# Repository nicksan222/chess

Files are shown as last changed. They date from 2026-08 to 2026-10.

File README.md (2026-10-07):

<div align="center">

Chess logo: the smart chessboard seen from above, with a knight's move glowing through its tiles

# Chess

### A physical chessboard with software in its bones.

**64 magnetic sensors · 64 RGB lights · one Raspberry Pi · zero hidden magic**








[**Explore the hardware**](hardware/README.md) · [**Read the architecture**](docs/architecture.md) · [**Build from source**](docs/development.md) · [**Contribute**](CONTRIBUTING.md)

<a href="hardware/cad/generated/board-assembly-finished.png">
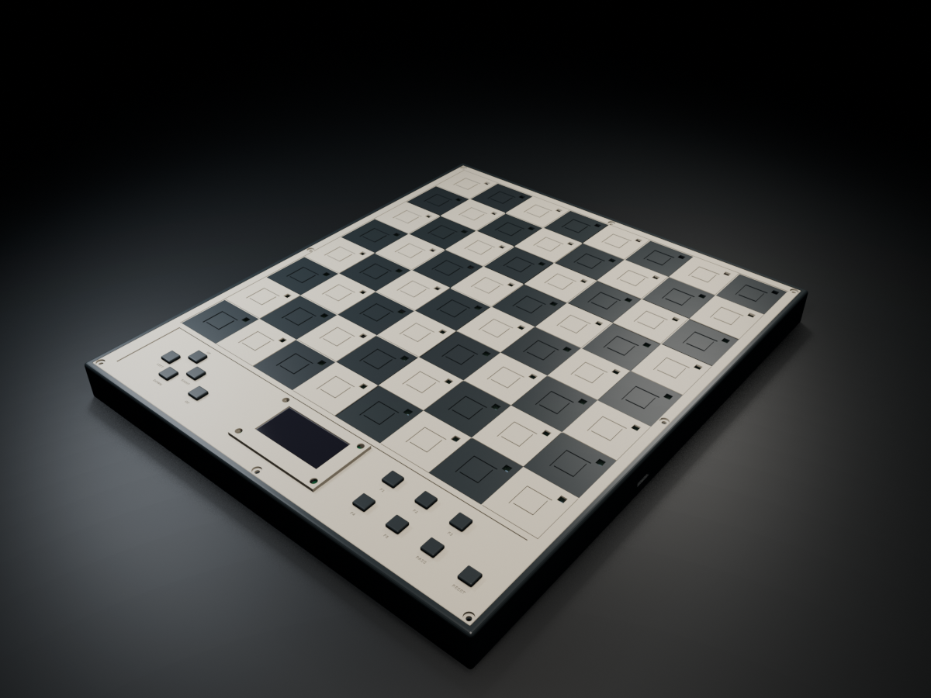
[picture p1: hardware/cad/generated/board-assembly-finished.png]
Generated Blender render of the finished open-source smart chessboard
  
</a>

<sub>Not a product mockup—the render above is generated from the <a href="hardware/cad/generated/board-assembly.blend">Blender assembly model in this repository</a>.</sub>

</div>

## About

Chess is an open-source smart chessboard designed to make the physical game
programmable. The design gives every square its own magnetic piece sensor and
clocked RGB light, ready to illuminate moves, threats, prompts, or entirely new
game modes. A Raspberry Pi Zero 2 W is intended to run the board directly in
Rust—there is no microcontroller, companion firmware, or private protocol in
the middle.

The interesting part is not only the board. Its mechanical dimensions,
electrical connectivity, firmware pin maps, KiCad project, Blender models, BOM,
and review images are generated from version-controlled contracts. Change a
measurement or signal once, regenerate, and let tests catch disagreement across
the stack.

| | |
|---|---|
| **Sense** | 64 DRV5032FC Hall sensors, eight compact polled TCA9554 banks |
| **Glow** | 64 individually addressable SK9822 RGB LEDs |
| **Think** | Raspberry Pi Zero 2 W targeting Rust on a Yocto Linux image |
| **Interact** | 12 labelled physical buttons and a 2.42-inch monochrome I²C OLED |
| **Build** | One 320 × 380 mm PCB, case, plate and twelve printable button caps |
| **Design** | Python contracts → KiCad 9 + Blender 4.5 + firmware mappings |

## Peek under the board

<table>
  <tr>
    <td width="58%">
      <a href="hardware/cad/generated/board-assembly-open.png">
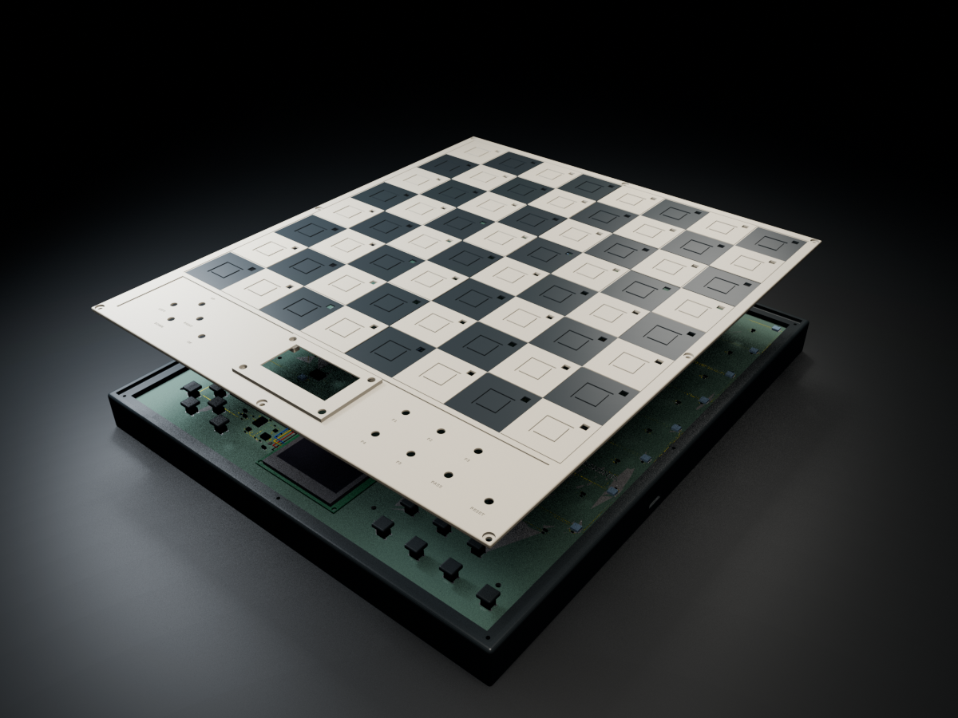
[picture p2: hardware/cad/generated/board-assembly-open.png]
Generated exploded Blender render showing the tile plate, PCB, and case
        
      </a>
    </td>
    <td width="42%">
      <a href="hardware/pcb/generated/board-top.png">
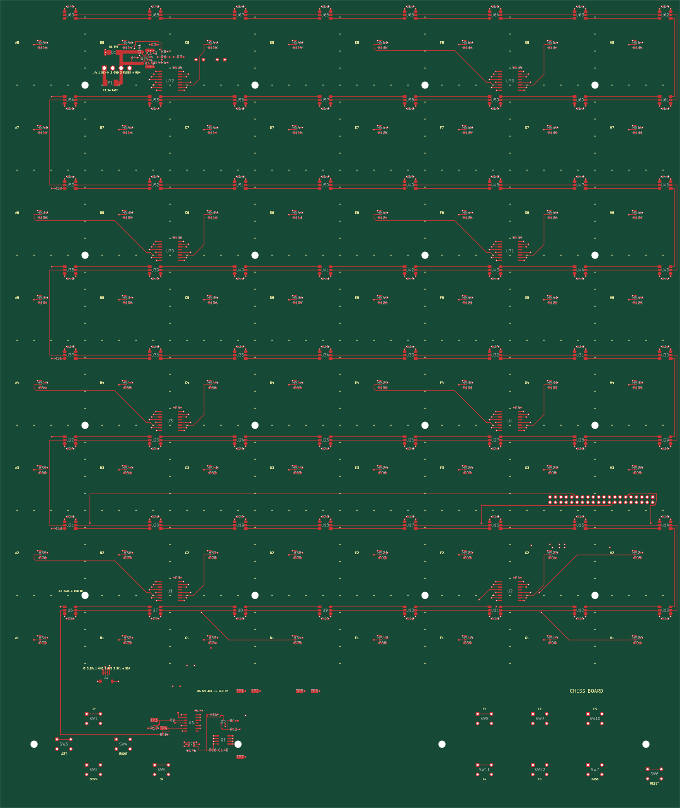
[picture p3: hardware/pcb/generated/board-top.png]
Generated KiCad top view of the smart chessboard PCB
        
      </a>
    </td>
  </tr>
  <tr>
    <td align="center"><strong>Two printed parts. One PCB. No per-square wiring harness.</strong></td>
    <td align="center"><strong>Every square gets a sensor and an LED.</strong></td>
  </tr>
</table>

The visuals are review artifacts, not hand-drawn diagrams. Open the
[Blender assembly](hardware/cad/generated/board-assembly.blend), inspect the
[KiCad board](hardware/pcb/generated/chess-board.kicad_pcb), browse the
[generated schematic](hardware/pcb/generated/schematic/chess-board.svg), or
check every exact part in the [generated BOM](hardware/pcb/generated/bom.csv).

## Why this is fun to hack on

| Hardware you can reason about | Software with clean seams | A workflow built for changes |
|---|---|---|
| No second processor and no opaque wire protocol. The Pi talks to I²C expanders, SPI LEDs, GPIO buttons, and the display directly. | The chess engine, menu model, persistence, and Pi application live in separate Rust crates. | One devcontainer pins Rust, Ruff, KiCad, Blender, and Just. CI checks code, connectivity, layout, CAD, and the AArch64 firmware graph. |

```mermaid
flowchart LR
    P["Magnetic pieces"] --> H["64 × Hall sensors"]
    H --> E["8 × TCA9554 banks (2×4)"]
    E --> PI["Raspberry Pi Zero 2 W"]
    PI --> R["Rust chess + board logic"]
    PI --> L["64 × RGB LEDs"]
    PI --> UI["OLED + 12 buttons"]
```

Read the [architecture notes](docs/architecture.md) for the boundaries and the
[hardware design](docs/hardware.md) for the component choices behind them.

## Repository tour

| Path | What is inside |
|---|---|
| [`apps/firmware`](apps/firmware) | The Raspberry Pi process, system integration, and Yocto image |
| [`crates`](crates/README.md) | Chess rules, menu state, persistence, logging, and shared Rust code |
| [`hardware/shared`](hardware/shared) | The source of truth for dimensions, parts, wiring, and mappings |
| [`hardware/pcb`](hardware/pcb) | PCB definition, routing, validation, KiCad project, and BOM |
| [`hardware/cad`](hardware/cad) | Parametric enclosure generators, Blender models, and renders |
| [`docs`](docs/README.md) | Architecture, fabrication, power, assembly, and development guides |

## Start hacking

Clone the repository, open it in the included
[development container](.devcontainer/README.md), and then use its pinned
toolchain:

```bash
just --list       # discover everything the repo can do
just precommit    # fast code + hardware validation
just generate     # regenerate CAD and PCB review artifacts
just check        # run routine repository-wide validation
```

Physical-release and Linux-image validation remain explicit, separate gates:

```bash
just pcb-release
just firmware-check
```

Prefer a smaller loop? Every app, crate, and hardware domain owns its own
`justfile`:

```bash
just --justfile crates/chess/justfile check
just --justfile hardware/pcb/justfile review
just --justfile hardware/cad/justfile generate
```

See [`docs/development.md`](docs/development.md) for the full workflow.

Coding assistants can use the existing [Pi setup](.pi/README.md) or the optional
[Claude Code / Herdr team](.agents/team/README.md). Rebuild the devcontainer,
run `claude auth login`, then `just agents-doctor` and `just agents`.
`just agents` starts the eight-role engineering team, including hardware, mechanical
and firmware engineers. Manufacturing, test and DevOps specialists are available on
demand; provider permissions remain on by default.

## Project status

> [!IMPORTANT]
> **The current design is ready for review, not yet physically proven.** The
> mechanical design and `D-PROTOTYPE` PCB generate successfully, and automated
> DRC, connectivity, schematic parity and modeled electrical checks pass;
> meaningful ERC still requires declared electrical pin roles. No
> complete board has been built yet. Prototype one sensor/LED square before
> ordering the full PCB.

The chess model and supervised firmware process exist. Hardware workers,
provisioning workers, and final physical validation are still open territory.
That makes this a particularly good time to challenge assumptions and shape the
project rather than only polish a finished product.

## Pick a quest

- **Firmware:** connect the Rust application to real Linux character devices.
- **Simulator:** make board behavior fast to test without a soldering iron.
- **Electronics:** review sensing, power, routing, and manufacturability.
- **Mechanical:** test clearances, print strategy, materials, and light diffusion.
- **Docs:** turn a pile of generated artifacts into a delightful build journey.

Start with [`CONTRIBUTING.md`](CONTRIBUTING.md), bring large ideas to
[Discussions](https://github.com/nicksan222/chess/discussions), and use the issue
forms for focused bugs or features. First-time contributors are very welcome.

---

<div align="center">

**Build it. Break it. Teach it a new game.**

Released under the [MIT License](LICENSE) · Please follow the
[Code of Conduct](CODE_OF_CONDUCT.md) · Report security issues via
[`SECURITY.md`](SECURITY.md)

</div>

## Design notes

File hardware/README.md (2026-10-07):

# Hardware

This directory contains the shared physical contract, manufacturable PCB, and
mechanical design:

- **`shared/`** — tool-independent dimensions, component identities, wiring,
  mappings, and host GPIO assignments.
- **`pcb/`** — reviewed connectivity, bill of materials, footprints, placement,
  routing, Gerber and Excellon fabrication output.
- **`cad/`** — printable enclosure and tile plate generated with Blender.

There is intentionally no separate electronics/schematic domain. The PCB is the
electrical design, and `pcb/board/board.py` composes its explicit connectivity
contract from typed components through the harness. The expanded netlist is generated output. Run `just --justfile hardware/pcb/justfile review` to validate and generate review and fabrication files. Manufacturing approval remains pending; `release` refuses approval.

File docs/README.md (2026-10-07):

# Project documentation

This directory contains design and development documentation that spans multiple
code or hardware areas. Component-local instructions stay with their component.

- [`architecture.md`](architecture.md) — how the parts relate, and why the board
  carries no microcontroller
- [`hardware.md`](hardware.md) — the board: sensing, LEDs, bus assignment
- [`fabrication.md`](fabrication.md) — how Gerbers are generated, and what the
  toolchain does and does not verify
- [`power.md`](power.md) — the 5 V rail and where the current goes
- [`cad.md`](cad.md) — printed parts and mechanical conventions
- [`host.md`](host.md) — the software on the Raspberry Pi, including WiFi setup
- [`assembly.md`](assembly.md) — what to order and the order to solder it in
- [`bring-up.md`](bring-up.md) — the ordered first-article checklist for the board
- [`development.md`](development.md) — the supported repository workflow

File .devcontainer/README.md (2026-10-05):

# Development container

This directory owns the reproducible VS Code / Cursor development environment.
The Dockerfile installs every toolchain the jobs need: Blender, KiCad 9, Ruff,
and the Rust components. Open the repository and run **Dev Containers:
Reopen in Container**, or drive it from the
[`devcontainer` CLI](https://github.com/devcontainers/cli):

```sh
devcontainer up --workspace-folder .
devcontainer exec --workspace-folder . just pcb
devcontainer exec --workspace-folder . just cad
devcontainer exec --workspace-folder . just quality
devcontainer exec --workspace-folder . just test
devcontainer exec --workspace-folder . just check
```

The image provides:

- Node.js 22, Bun 1.4, and every agent harness: pinned Claude Code and Herdr in the
  image, pinned [Pi](https://pi.dev/) and Codex installed during container creation
  (creation fails if any is missing), plus Herdr's Claude/Codex/Pi status hooks and
  the Reviewr panel; `just agents` asks whether the optional
  [agent team](../.agents/team/README.md) runs in Claude Code or Pi;
- a Bun-managed `.pi` TypeScript project with pinned Pi API types, workspace
  IntelliSense, and `bun run --cwd .pi check` validation for project extensions;
- stable Rust with `rustfmt`, Clippy, Just, and the AArch64 GNU target/linker;
- Ruff for CAD, PCB, and shared Python;
- KiCad 9 with `kicad-cli` and `pcbnew`;
- a checksum-verified Blender at `/opt/blender`;
- X11/GL/EGL, Mesa, Xvfb, and `xauth` so headless Blender can render;
- an in-container Docker daemon for Yocto metadata validation, plus native build,
  USB, and udev development libraries;
- rust-src, Pylance, YAML, ShellCheck, Docker, Cargo.toml, TOML, LLDB,
  Markdown, and GitHub Actions editor integration.

CI prebuilds this image, pushes it to GHCR, then runs Python, CAD, PCB, and Rust as
parallel `devcontainer exec` jobs against that digest. Subsequent
prebuilds reuse the image layers when the Dockerfile is unchanged.

Container creation configures the repository pre-commit hook, installs Pi/Codex,
and configures Herdr integrations without starting models. Claude Code is installed
in the image. Separate `chess-claude`, `chess-codex` and `chess-herdr` volumes keep
provider credentials and runtime configuration across rebuilds. Run
`claude auth login` inside the container (or forward `CLAUDE_CODE_OAUTH_TOKEN`).
Accept workspace trust manually. Host API credentials may select API billing;
unset `ANTHROPIC_API_KEY` before opening the container for subscription-only use.
No host credential directories are mounted and no secrets are copied into the image.
Credentials for every built-in Pi API-key provider are forwarded from matching
host environment variables without writing secrets to the repository. Pi's
`~/.pi/agent` directory uses the persistent `chess-pi-agent` Docker volume, so
credentials created with `pi` and `/login` survive container rebuilds. The
`pi-worktrees` package stores managed worktrees in the persistent
`chess-pi-worktrees` volume, preserving uncommitted agent work across container
recreation. Export provider variables on the host before opening the container; see Pi's
[provider documentation](https://github.com/earendil-works/pi-mono/blob/main/packages/coding-agent/docs/providers.md)
for the supported names and cloud-provider settings.

Host-only fallback downloads (`.cache/blender`, `.cache/pcb`) exist for people
who run the tools outside the container.

After create, the first VS Code terminal greets you with a 👋 welcome: toolchain
versions, which agents are signed in, and the commands below. Bring it back with
`just welcome`.

```sh
just welcome               # toolchain/login status and starter commands
bun run --cwd .pi check    # type-check project Pi extensions
pi                         # start the coding agent; use /login for OAuth
claude auth login          # persistent Claude login; no automatic sign-in
just agents-doctor         # tools/login check, no model request
just agents                # start the eight-role team
just agents-restart        # restart it, task handoff kept
just agents-stop           # stop it
just agents-test           # offline launcher/configuration tests
just pcb                    # test, then generate PCB review output
just cad                    # test, then generate CAD output
just quality                # lint and format-check every package
just firmware-binary        # link the firmware for AArch64
just test                   # test every package
just check                  # all domains, sequentially
```

Host-specific device access and hardware flashing policy do not belong in the
portable baseline container configuration.

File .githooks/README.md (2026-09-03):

# Git hooks

This directory owns version-controlled Git hooks. The pre-commit hook runs
`just precommit`, which composes package-owned recipes while skipping CAD
renders and PCB fabrication output. `.pre-commit-config.yaml` invokes the same
gate for `pre-commit run`.

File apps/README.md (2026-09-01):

# Applications

This directory contains runnable applications. Reusable concepts belong in shared
crates rather than application packages.

`firmware` is the Raspberry Pi Linux appliance and its product process. The
board carries no microcontroller or bare-metal target; see
[`../docs/architecture.md`](../docs/architecture.md).

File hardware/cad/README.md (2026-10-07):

# Mechanical design

CAD follows the PCB domain: concrete components, one composed board, a reusable
harness and generated output. Shared dimensions remain in `hardware/shared`.

```
components/  one physical component per file; printable parts and electronics
board/       Board definition, the single generate.py entry point, specific tests
harness/     registry, Blender geometry/rendering, validation and automatic checks
generated/   owning .blend models, assembly, PNGs and verification manifest
```

`board/board.py` owns the case, plate, imported PCB assembly, off-board host and
OLED, rear jack, rocker, mating plug envelopes and all eight harness conductors. Repeated PCB parts remain individually selectable by square or control name:
`board.sensors["A1"]`, `board.leds["H8"]`, `board.buttons["OK"]`.
The PCB generator attaches package-local STEP models and exports `chess-board.glb`.
Blender imports that file's substrate, holes, copper, artwork and component meshes;
it does not rebuild PCB electronics. Component references survive as `PCB_SW1`,
`PCB_SW1_Body`, etc. Package geometry and model fidelity belong to PCB definitions.
Most models are explicitly dimension-based envelopes; the switch has its declared
housing and actuator. Detailed supplier CAD and physical validation remain pending.

Shared supplier dimensions, mounting interfaces and layout measurements remain
readable source definitions. CAD uses them for enclosure fits and off-board
parts; it does not infer these values from imported Blender mesh bounds.

There are fourteen printed parts: twelve button caps plus the case and plate. `components/printable/board_case.py` owns the
344 × 404 × 30 mm open case; `tile_plate.py` owns the 335 × 395 mm checkerboard
and control bezel, including its raised screen and underside mounting ledges. Their cuts, supports, screw positions and assembly coordinates
retain their positions. Each square has an 18 × 18 mm square ring channel,
0.8 mm deep, surrounding a 14 × 14 mm island at the square's original surface
height. A solid 19.6 × 19.6 mm underside support covers the Hall sensor and
reinforces the channel floor. Future pieces use a matching square ring foot:
17.5 mm outside, 14.5 mm inside, projecting 0.6 mm below the base. Both interfaces
come from `shared/dimensions/tile_plate.py` and include clearance on both sides.

Each LED has a 4.6 mm square through-window above its actual emitter position.
Controls use a left D-pad, separate OK, a right function group (F1-F5 and PASS),
and an isolated Reset. Positions and render legends read the same shared button
identities used by the PCB and GPIO mapping; moving switches requires regenerating
both PCB and CAD; CAD generation automatically refreshes a stale PCB export.

The 60 mm control strip is recessed 1 mm. A 2.42-inch MC242GW monochrome OLED
uses the same four-wire I²C interface and 128 × 64 graphics API. The module's
supplied pin header is omitted: solder the harness directly, leaving RES open
for the module's onboard reset circuit. Its screen sits above the panel in a
bezel, with four carrier mounting ledges and blind screw pilots and four top access holes. Carrier, glass,
mounting holes and underside envelopes follow the supplier drawing. Screw size,
print tolerances and retention still require a physical prototype.

Twelve separate printable caps fit the existing TL1105 switch stems. Their
labels are recessed into the actual panel mesh. D-pad, OK, function buttons,
PASS and RESET share their coordinates with the PCB and GPIO definitions.
The four OLED conductors remain 180 mm long with dressing/service slack.
Square faces and locating channels use charcoal and ivory presentation materials.
The assembly imports those exact meshes rather than rebuilding
them. Coordinates are centered on the playing area; PCB coordinates are translated
once on the imported KiCad assembly, converting glTF metres to our millimetre scene.

## Generate and check

```sh
just --justfile hardware/cad/justfile check-fast  # lint, types and Python tests
just --justfile hardware/cad/justfile generate    # complete models and renders
just --justfile hardware/cad/justfile check      # both
```

`board/generate.py` checks PCB/shared source fingerprints, actual exporter versions,
and hashes of the saved PCB, GLB and PCB-owned `pcb-components.json`. CAD source
provenance includes its `justfile` and the shared `hardware/build_support.py` publisher.
The selected Blender executable is queried directly and publication verifies that the
worker recorded the same runtime version. Missing, altered or stale output triggers the full checked PCB pipeline.
All expected component references must have meshes in the GLB. The current export,
its `3d-models.json` fidelity/provenance report, and its validated metadata snapshot
cross the host Python / Blender Python 3.11 boundary. Run inside the devcontainer,
which supplies KiCad, CadQuery 2.6.1 for STEP generation, and Blender 4.5.

`just generate` and CI run PCB review before CAD, using the same checked export.
The standalone CAD command refreshes that dependency only when needed. CI runs
one sequential hardware job and retains separate successful PCB and CAD outputs.

The generator builds the case, builds the plate, assembles their saved models,
checks fit, renders the finished/open views and writes `manifest.json`. It publishes
one complete artifact set atomically; a failed model, render, check or missing output
leaves previous output untouched. Do not hand-edit generated files.

Board-specific dimension/instance tests live in `board/tests`. Generic registry,
publication and clearance checks live in `harness`, including negative regressions.
Every build checks actual PCB body heights, connector mating envelopes, case/bay
clearance, positive/manifold printable meshes, build volume and seated assembly fit.
The fit manifest records measured mesh dimensions, volumes and intersection results.
`board/tests/blender` runs inside the generation worker on the actual seated meshes,
checking all 64 square seats and LED windows, the lowered strip, button protrusion,
display sight line and render visibility. Electronics tests check actual positions,
rotations, mounting sides and body dimensions of every PCB instance, plus the
shared host/display dimensions, plus native PCB mounting holes and artwork.
The importer welds coincident shading vertices without moving the surface and
requires closed positive-volume solids before intersection checks. The worker saves
the finished inspection view, reopens that exact `.blend`, and only then runs the
native tests. Host pytest skips these native tests; every generation must run them
without skips before it publishes.

## Blender harness

`harness/base/blender` owns mesh operations, materials, studio setup, saving and
rendering. Boolean batches require disjoint cutters, and bevel radii must stay
below half the thinnest dimension: these prevent silent invalid geometry.
Materials are presentation choices rather than manufacturing specifications.

The pinned Blender toolchain uses a private Xvfb display when available. The
`setup` recipe can download a checksum-verified build into `.cache` outside the
container; `BLENDER_BIN` selects an existing installation. Ruff and strict
Basedpyright use Blender stubs; normal declarations and checks run without Blender.

Both printed parts exceed desktop printer beds and are intended for an FDM service.
Mesh checks do not prove shrinkage, supports, layer adhesion or physical operation.
Calibrated prints and physical clearance review remain pending; generated models
are review artifacts and do not constitute manufacturing approval.

The PCB generator owns the metadata snapshot as well as the meshes. CAD only
copies and reads the checked bundle; it validates the copied files and retries
once if concurrent PCB publication interrupts the copy. The frozen input GLB is
retained with the CAD outputs so the assembly can be reviewed independently.
`manifest.json` fingerprints CAD/shared source inputs and hashes every output,
including the snapshot. Atomic publication rejects missing or altered artifacts.

Rear power components and mating plugs use simplified dimension envelopes.
Every harness conductor retains its connector cavity, net, cut length and
proposed route length. Mesh checks cover enclosure, PCB and off-board collisions,
except same-reference solids and declared mating interfaces. An AABB broadphase
selects possible collision pairs before mesh booleans; remaining checks use a
0.01 mm³ numerical-noise tolerance, with connector endpoint allowances applied only
at their declared mating interfaces.
Unmodeled service slack, actual solder-pad locations on the OLED, cable bend radii,
connector latches and final wire dressing remain physical assembly checks.

The OLED mount uses four [M2.5 × 3 DIN 912 socket screws](https://www.newstarfastenings.com/en-gb/products/m25-x-3-socket-cap-screw-din-912-steel-129-self-finish),
with 4.5 mm heads and a 2 mm hex driver. The bezel's 5 mm access holes allow
installation from above. Calibrate/drill and tap the printed 2 mm pilots to M2.5
before installing the carrier; verify thread holding and screw-tip clearance on
a prototype. Screw models are not included in the electronics envelope render.

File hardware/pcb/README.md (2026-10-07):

# PCB authoring

The PCB has three source folders:

- `components/`: one concrete component per file, including its purchasing facts,
  land pattern and named connections to physical pins.
- `harness/`: reusable circuit declarations, SPICE conversion, native KiCad
  rendering and automatic component checks. KiCad type stubs live in
  `harness/typings/`.
- `board/`: just `board.py` (components, placement, layout and rules),
  `wiring.py` (copper intent), and `generate.py` (the single output pipeline).
  `board/tests/` holds specific electrical behavior tests using the harness.

`generated/` contains output, not source. Generate inside the devcontainer:

```sh
just --justfile hardware/pcb/justfile generate
# or
PYTHONPATH=hardware python3 -m pcb.board.generate
```

Open `generated/chess-board.kicad_pro` in KiCad. Generation writes the PCB,
connection schematics, BOM, expanded netlist, placement CSV, PDF/SVG/PNG previews,
ERC/DRC findings, a native `chess-board.glb` assembly, portable component STEP
models, `3d-models.json` provenance/fidelity, a manifest, and `chess-board-fabrication.zip`. The ZIP contains
all eight copper layers, masks, silkscreens, outline, paste layers and separate
plated/non-plated Excellon drill files. It validates exported schematic pin maps and
schematic/PCB parity before atomically replacing previous output.

The board owns its eight-layer stackup, four rail planes, mounting holes and
silkscreen in `board/board.py`. `board/wiring.py` declares routing intent with
`NetRoute` records (layer choices, widths and local areas); the harness supplies the obstacle-aware
multilayer router. Exact paths use `CopperPath` through named component pins.
`RoutingPlan` orders power connections, LED links and signal routes; execution lives entirely
in the harness. Package escape geometry and local clearance rules belong to each
component definition. There is no native routing implementation under `board/`.
Connections come from the components' pin maps. Generation checks native routed connectivity
and exports full-board copper SVGs and matching PNGs (using `rsvg-convert`).
`board-connections.svg` remains a separate logical airwire view.
Board pytest tests run ngspice against actual sensing and button components and
their pin maps. They cover every square, piece placement/removal, a move between
banks, startup bypass charging, crossed inputs, individual button presses,
three simultaneous presses, all buttons held, bounce and release. Button checks
explicitly supply an external 3.3 V bias through a declared source resistance;
this represents host GPIO pull-ups, not additional PCB components or guaranteed
Pi pull-up limits. Both `check` and generation collect all board tests with pytest.
Generation writes `electrical-checks/results.json`, `junit.xml` and `tests.log`;
failed, skipped or empty suites stop the export. Run them directly with
`python3 -m pytest hardware/pcb/board/tests` inside the devcontainer.
The models are ideal: magnetic margins, sensor sampling delay, I2C, firmware
debounce and electrical behavior outside the sensing/button circuits remain untested.

```sh
just --justfile hardware/pcb/justfile check          # lint, types, harness/catalog checks
just --justfile hardware/pcb/justfile review         # check, then generate authoring output
just --justfile hardware/pcb/justfile harness-tests
just --justfile hardware/pcb/justfile component-tests
just --justfile hardware/pcb/justfile component-checks
just --justfile hardware/pcb/justfile pr-report main
```

Automatic checks live in [harness/checks/](harness/checks/README.md). Documentation
checks use real HTTP requests. Shared products, dimensions and electrical
contracts in `hardware/shared/` remain authoritative.

Pin electrical roles, reassessed manufacturing constraints,
detailed supplier geometry, active-device simulations and physical evidence are still
pending. Previous engineering assumptions are retained in
[engineering assumptions](../../docs/pcb-assumptions.md) for reassessment, not as proof of
the new design. Fabrication files are generated locally for review; manufacturing
approval remains pending. The separate release command still refuses approval.

Repeated components are created in loops as separate instances. Select them by
square or bank: `board.sensors["A1"]`, `board.leds["H8"]`,
`board.sensor_bypasses["A1"]` or `board.sensor_banks["A1-D2"]`.
Their own pin maps remain the source of electrical connectivity. Routing can be
changed for one sensor without defining another component or reconnecting it:

```python
from dataclasses import replace
from shared.electronics.hall_sensor import HallSensorPin

sensor_net = board.sensors["A1"].net(HallSensorPin.ACTIVE_LOW_OUTPUT)
board.wiring = tuple(
    replace(route, width_mm=0.4) if route.net == sensor_net else route
    for route in board.wiring
)
```

The 3D pipeline is owned by the PCB harness. `ComponentDefinition.model_3d`
optionally declares package-local colored solids. Other products receive an
explicitly labeled envelope from their existing body dimensions. CadQuery writes
one STEP per product; the harness attaches `${KIPRJMOD}/models/...` references to
native footprints. KiCad then supplies board-side placement, rotation, mounting
height, holes, copper and artwork in the GLB. Missing component meshes fail the
export. CAD imports that exact artifact instead of maintaining electronic bodies.
These models do not claim supplier detail or physical manufacturing validation.

The PCB export also owns `pcb-components.json`: component bodies, mating envelopes,
contact positions and named sensor/LED/control groups for the Blender bridge.
`3d-models.json` binds that snapshot, native PCB and GLB to source and exporter
version fingerprints. Portable `Model3D`, `Solid3D` and `MatedZone` values are
available through `pcb.harness`; native conversion stays under `pcbnew`.

Assembly review outputs include `assembly-bom.csv` (grouped quantities, MPNs and
mounting types), `assembly-smd.csv` and `assembly-through-hole.csv` (disjoint
placement lists). `positions.csv` retains native XY/rotation conventions and adds
package identity from component definitions. `harness.md` and `harness-bom.csv`
cover the separate off-board wire assemblies. See `generated/assembly.md` for
assembler interpretation and the outstanding release requirements.

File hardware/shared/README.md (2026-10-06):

# Shared hardware definitions

This directory is the tool-independent contract between hardware domains.

- `dimensions/` separates shared measurements by physical object: `board.py`,
  `case.py`, `panel.py`, and `tile_plate.py`. `printing.py` owns process limits;
  `validation.py` checks fit across those objects. PCB routing rules and CAD
  presentation settings remain in their own domains.
- `components/<part>.py` owns each approved product: manufacturer, exact MPN,
  package, body metadata, and datasheet link. The package registry enumerates them.
- `electronics/` owns tool-independent component families and typed pin semantics,
  including `harness.py`, the cavity-by-cavity definition of the off-board power and
  OLED wiring harnesses (tests, BOM and `generated/harness.md` all read it).
- `dimensions/unverified.py` lists case/CAD dimensions that still rest on an unread
  datasheet or an unmeasured drawing; the PCB release gate imports it.
- `panel_buttons.py` owns each control button's position, typed header pin,
  switch reference, and routing priority.
- `hall_banks.py` owns compact bank membership, P-port order, labels, and address
  straps; dimensions and wiring consume it.
- `wiring.py` owns net names, host GPIO assignments, square-to-sensor mapping,
  and LED chain order.

Shared code must never import Blender, Schemdraw, Gerbonara, or KiCad. Domain
folders compose these definitions and own only rendering/tool behavior.

Shared Python is linted and format-checked with Ruff and strictly type-checked
with Basedpyright. Both explicit and inferred dynamic types are rejected. Run
`just --justfile hardware/shared/justfile check`; the root
`just precommit` and `just check` recipes compose it with the other packages.

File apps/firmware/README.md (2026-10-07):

# Firmware

This app contains the Raspberry Pi process and its Yocto build. The development
container includes the AArch64 linker and Rust target used by CI.

```sh
# Compile and link the complete Rust dependency graph for the Pi architecture.
just firmware-binary

# Validate or build the Yocto image; these commands require Docker.
just --justfile apps/firmware/justfile image-check
just --justfile apps/firmware/justfile image
```

The flashable files are written to `dist/firmware`.

## Runtime architecture

`src/runtime/` is the one event-driven application loop used by both the
executable and the runtime tests. Hardware adapters publish typed physical observations
through `src/events/`; Tokio channels never escape that module. `src/harness.rs` starts
the same runtime without physical adapters and provides an acknowledged
`trigger` operation, so tests never race the event loop or duplicate production
behavior.

`just --justfile apps/firmware/justfile test` runs unit tests and `tests/`: the
production runtime with injected hardware (`tests/runtime/`), display rendering
(`tests/display/`) and the command line. It needs no Docker or hardware. Scripted
GPIO cases cover all 12 button mappings, bounce, initially held buttons and read
failures. Product logic above the Linux adapters is tested against in-memory
fakes; the adapters themselves (NetworkManager through `nmrs`, GPIO through
`gpiocdev`) run only on the board, where real Wi-Fi, GPIO and display behaviour is
validated.
The Linux GPIO reader is available to callers but is not yet wired into the
production executable's startup.

`src/connectivity/` owns typed, presentation-agnostic Wi-Fi control. Its
`Connectivity` API reports status, scans access points, manages the WPA
provisioning hotspot, and joins open or WPA Personal networks. Product code sees
validated SSIDs, redacted passphrases, and domain results rather than command
arguments or NetworkManager types. The implementation uses the maintained `nmrs` D-Bus
client; no shell or `nmcli` process is involved. The Yocto image
includes NetworkManager Wi-Fi support, `wpa-supplicant`, and `dnsmasq` for
NetworkManager's shared hotspot mode. Captive-portal presentation and menu
transition wiring remain separate consumers of this module.

`src/menu/definition.rs` is the single product menu definition. It composes the
headless `menu` crate's primitives into the Play, Connection, Pairing, Update,
and Settings submenus. Leaf requests are typed but deliberately immediate and
non-blocking until their external modules define completion and cancellation
behavior; the menu crate remains product-neutral and performs no operation.
Each request has one placeholder integration file under `src/menu/transitions/`,
so future module ownership has an explicit location without entering the menu
definition or runtime loop.

`src/hardware/buttons.rs` and `src/hardware/debounce.rs` own polling, active-low
translation, and mechanical debounce. Call `start_subscription` with a GPIO
reader, then await `on_message` for debounced pressed/released transitions.
`hardware::linux_gpio::LinuxGpioReader` requests inputs with internal pull-ups
on a caller-selected Linux GPIO chip; the button adapter interprets a low level
as pressed. `with_external_bias` leaves line bias to the board instead of
requesting an internal pull-up. Callers do not inspect GPIO levels.

`src/hardware/display/` constructs a buffered SSD1309 driver for the installed MC242GW
2.42-inch 128×64 OLED at address `0x3C`. The four-wire I²C module supplies
power-on reset; allow 200 ms of stable power before initialization. Construction
and drawing perform no I/O; initialize, clear, flush and power retain the same API. It is
intentionally not attached to the runtime yet. Integration tests under
`tests/display/` capture the exact data packets emitted through I2C, decode the
transmitted frame, and compare it pixel-for-pixel with the externally maintained
`embedded-graphics-simulator`. Every display test writes a PNG result beside
the tests in `tests/display/screenshots/`.

The simulator verifies frame contents, not controller command semantics. Wokwi
can emulate an SSD1306 receiving real I2C traffic, but running this Raspberry Pi
firmware driver there requires a separate supported-microcontroller harness and
Wokwi CI credentials. No such harness is checked in because it would not execute
the production Pi I2C adapter.

The remaining hardware workers are not implemented yet. The board contract uses
polled TCA9554 input-port reads at eight addresses, not a GPIO sensor interrupt;
see [host acquisition](../../docs/host.md#reading-the-board). Reusable,
function-named GPIO identities and type-safe descriptors live in
`src/hardware/pins.rs`; OS-backed implementations live alongside them (currently
`src/hardware/linux_gpio.rs`). Unused header functions are deliberately absent.
`BoardPins` describes the three interfaces in the hardware wiring contract:
I2C for the shared bus, SPI for the LED chain, and direct GPIO button lines.

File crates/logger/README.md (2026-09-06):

# Logger crate

This `no_std` crate is the project's headless logging contract. It performs no
I/O and selects no platform backend. Firmware and tests
implement `Logger` and register one process-wide instance during startup.

Records contain a severity, routing target, source module/file/line, and
allocation-free `core::fmt::Arguments`. The `error!`, `warn!`, `info!`,
`debug!`, `trace!`, and level-selectable `log!` macros evaluate message
arguments only when the backend enables the record.

```rust
use logger::{Logger, Record, info, register};

struct RaspberryPiLogger;

impl Logger for RaspberryPiLogger {
    fn log(&self, record: Record<'_>) {
        // Forward to journald, stderr, a serial adapter, etc.
        let _ = record;
    }
}

static LOGGER: RaspberryPiLogger = RaspberryPiLogger;
register(&LOGGER)?;
info!(target: "firmware", "board ready");
# Ok::<(), logger::RegistrationError>(())
```

Backends own filtering, formatting, synchronization, buffering, and flushing.
`NopLogger` is supplied for callers that deliberately discard all diagnostics.

## Registration

A hosted application can register one static logger during startup:

```rust
use logger::{LevelFilter, implementations::SystemdLogger, register};

static LOGGER: SystemdLogger = SystemdLogger::new(LevelFilter::Info);
register(&LOGGER)?;
# Ok::<(), logger::RegistrationError>(())
```

Shared crates use the same logging macros. Before registration they do nothing,
so logging remains optional. Registration is thread-safe, allocation-free,
`no_std`, and permanent; a different logger cannot replace the first one.

## Hosted implementations

Enable the `std` feature for two implementations kept in this crate:

- `implementations::SystemdLogger` writes syslog-priority-prefixed records to
  stderr, where the Yocto firmware's systemd service captures them in journald;
- `implementations::StderrLogger` writes human-readable records for terminals,
  desktop applications and development tools.

They are separate concrete types in separate source files, so their `Logger`
implementations do not overlap or collide. Both default to `LevelFilter::Info`
and accept a different maximum level through `new`.

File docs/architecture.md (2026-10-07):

# Architecture

## Purpose

Describe how the parts of the system relate, and why the boundaries fall where
they do.

## One processor

```text
        Physical Board
  64 Hall sensors, 64 LEDs, 12 buttons, OLED
              |
      I2C, SPI, GPIO  (no protocol)
              |
              v
      Raspberry Pi Zero 2 W
          chess -> bridge core
              |
              v
         Local Adapter
```

The board carries no microcontroller. A Raspberry Pi Zero 2 W reads the sensors
and drives the LEDs directly, so there is no second processor, no microcontroller
firmware, and no wire protocol between the sensing hardware and the game logic. The
Pi plugs into a socket on the underside of the single PCB and hangs beneath it.
(`apps/firmware` is the software that runs on the Pi, not a second target.)

That absence is the point. A microcontroller — even one with deliberately frozen,
fixed-function firmware — would mean a second toolchain, a cross-compilation
target, a flashing procedure and a register map that two codebases have to keep
agreeing on. Removing it removes all four. See [`hardware.md`](hardware.md) for
the two component choices that make it possible.

## Layers

- **`crates/chess`** is the game: board state, move generation, history. It has
  no idea a physical board exists.
- **`crates/core`** holds small integration-neutral building blocks.
- **`crates/menu`** owns the board's headless menu definition and the reusable
  cursor and navigation model behind it. Input mapping and presentation remain
  adapters in the applications.
- **`apps/firmware`** owns everything shipped to the Pi: the Rust process,
  Yocto configuration, character devices, display, buttons, network provisioning,
  and systemd units.

Offline chess behavior is the initial focus. Integration-specific code stays in
adapter directories, so additional adapters can be introduced without changing
bridge core or the shared crates.

## Mechanical shape

One PCB carries the sensors, LEDs, buttons and display connector; two printed parts
enclose it: an open-tub case that holds the board and the Pi, and a tile plate over the
whole board that also forms the control bezel. Twelve printed caps sit on the PCB switches. The 5 V supply enters through a panel
jack and rocker in the case's rear wall, wired to the board. See [`cad.md`](cad.md) and
[`power.md`](power.md).

## Where the contracts are

- **The physical stack.** `hardware/shared/dimensions/case.py` decides the heights
  that let the plate sit flush over the board, and validates that they sum
  correctly on import.

## TODO

Design the bridge-to-adapter message set. None of it is selected yet.

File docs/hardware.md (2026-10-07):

# Hardware design

D-PROTOTYPE is a fixed-function sensor-and-light PCB connected directly to a Raspberry
Pi Zero 2 W, which hangs under the board and plugs into a socket (J1) on the board's
bottom side. There is no microcontroller and no separate schematic source tree.

## Sources of truth

- [`hardware/shared/wiring.py`](../hardware/shared/wiring.py) owns net names,
  GPIO assignments, expander mapping, and LED chain order.
- [`hardware/shared/components/`](../hardware/shared/components/) contains one
  approved-product file per part, with its identity and physical package metadata.
- [`hardware/shared/dimensions/board.py`](../hardware/shared/dimensions/board.py) owns
  the playing grid and PCB envelope; the neighboring case, panel, and tile-plate
  modules own their physical measurements.
- [`hardware/pcb/board/board.py`](../hardware/pcb/board/board.py) composes
  the component instances and their declared connectivity.
- [`hardware/shared/electronics/harness.py`](../hardware/shared/electronics/harness.py)
  defines the off-board wiring harnesses (power entry, OLED) cavity by cavity.
- [`hardware/pcb/generated/bom.csv`](../hardware/pcb/generated/bom.csv) lists the
  PCB components. Off-board assembly output still needs migration.

The PCB implementation supplies footprints, placement, routing, and fabrication
output for those shared definitions. This avoids maintaining a drawing that can
drift from the board actually sent to fabrication.

## Architecture

Eight TI TCA9554DWR expanders read all 64 DRV5032FC active-low omnipolar Hall
sensors. Each owns a compact 2-rank × 4-file bank and all eight P0–P7 inputs. Sixty-four Opsco SK9822-A LEDs (GRB colour order, budgeted at 18 mA per channel) form a serpentine
SPI chain beginning at A1, powered from a switchable `LED_5V` rail that is off at boot (see
[power](power.md#led-rail-switch)); the Pi's 3.3 V SPI clock and data reach the 5 V
chain through a 74AHCT125 buffer (U5, held off by a SN74LVC1G97 gate, U75, until the LED rail is up) and a 56 Ω series resistor (R9) that damps the
first link. Later LED links run over a plane reference, and the three left rank-turn
data links carry their own 56 Ω series resistors (R10-R12). Twelve E-Switch TL1105CF100Q panel buttons
connect to dedicated Pi GPIO lines, and an SSD1309 OLED module on the shared I²C
bus is wired to a JST SH header (J2) and sits in the tile plate's bezel.

`hardware/shared/hall_banks.py` defines bank membership, input order, address
straps, and labels once. Shared dimensions derive placement from bank geometry
and package/LED clearance; PCB generation composes and validates the typed electrical graph
against that mapping. CAD depicts the same eight package obstructions.

Banks use 0x20–0x27; the OLED remains 0x3C. Acquisition is polled, with each INT
and GPIO4 explicitly no-connect. See [host acquisition](host.md#reading-the-board)
for register setup, non-atomic scans, pull-up assumptions, and required testing.
The SOIC-16W land pattern follows TI DW0016A (SCPS233E pp. 39–40): 1.27 mm pitch,
9.3 mm pad-row spacing, 2.0 × 0.6 mm lands. This is not a scaled old package.

## Power entry and bottom side

The 5 V supply enters through a panel jack and a panel rocker in the case's rear
wall, wired to a JST VH header (J4) on the board; see [power](power.md) for the eFuse protection (the rocker
switches the eFuse's enable signal, not the load). Only
through-hole parts sit on the bottom side: J1 (the Pi socket), J4 and the two bulk
capacitors. Everything else is top side.

## Buses and LED lines (S5)

- **I²C:** the PCB has no pull-ups (R1/R2 removed). The Pi supplies 1.8 kΩ;
  the approved MC242GW module adds 4.7 kΩ on each line to its 3.3 V logic rail
  ([supplier schematic](https://www.lcdwiki.com/res/MC242GX/2.42inch_IIC_Module_MC242GX_Schematic.pdf)).
  Their nominal parallel resistance is 1.30 kΩ: the existing capacitance estimates
  of 243 pF SDA / 230 pF SCL imply about 268 / 254 ns rise time using 0.8473RC,
  with about 2.23 mA sink current at 0.4 V. These are estimates, not measured bus
  timing. Firmware retains the Pi's default **100 kHz**; this change does not qualify
  400 kHz. Verify the supplied module variant and measure the populated bus.
- **LED lines:** the LED rail is an inner plane, so the outer-layer links are
  referenced to it. The first data link (through R9) and the clock stay within the
  SK9822's input range at 4.5 V and 5.25 V in simulation (lossless-line model, assumed
  25-100 Ω driver, 1-3 ns edges). Rank-turn links are plane-referenced. The three left
  rank-turn data links (LED_D16/D32/D48, on an inner layer) were out of range without
  a terminator and pass with R10-R12 (56 Ω, 3 mm after each LED's data output). Edges
  settle in at most about 6 ns, well inside the SK9822-A's 30 MHz serial limit.
  The SK9822-A's driver strength is not in its datasheet, so a bench scope of LED_D16 at
  the SPI clock remains. Test points TP3/TP4 sit next to U5/R9. The datasheet's
  optional 500 Ω series resistors are not fitted. R9 is kept as margin; R17/R18 (10 kΩ) hold LED_DATA_5V and LED_CLK_5V low while the buffer is off. The SPI clock
  is limited to 10 MHz, which leaves a worst-case data setup margin of about 33 ns
  against the SK9822-A (about 1.5 ns would remain at 30 MHz).

The single PCB retains its validated eight-layer, 1.6 mm stackup. No compatible
layer reduction or physical operation has been established. Hall routes are
confined to their bank rectangles; native-board tests separately bound copper
length and footprint-centre distance rather than conflating them.

## Validation

Run:

```sh
just --justfile hardware/shared/justfile check
just --justfile hardware/pcb/justfile review
```

PCB checks cover component declarations, pin maps, package geometry, documentation
URLs and native PCB checks. Generation requires zero routed-copper DRC violations,
unconnected pads and schematic parity mismatches. Board pytest/SPICE scenarios
cover Hall sensing, bypass charging and button presses, chords, bounce and release.
Power-path, ampacity, bus timing and firmware pin parity checks still need migration;
older calculated figures in these documents are retained assumptions, not current
validation. See the [PCB README](../hardware/pcb/README.md).

`just pcb-release` currently refuses manufacturing approval. Review the
[engineering assumptions](pcb-assumptions.md) and record real prototype evidence
before treating the generated files as a physically validated design.

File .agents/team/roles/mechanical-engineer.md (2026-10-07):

# Mechanical engineer — enclosure, fit and optical stack

## Read before matching work

- `hardware/cad/README.md`, `hardware/shared/README.md`.
- `docs/cad.md`, `docs/assembly.md` and `hardware/cad/README.md` and the owning `hardware/cad/components/` definition.

## Scope and boundaries

Own assigned case/tile-plate Python generators, printable geometry, fasteners, board
supports, Pi/control clearances, connector access, tolerance stack, FDM printability,
assembly/service access and light diffusion. Shared dimensions and coordinates belong
in `hardware/shared/dimensions.py`; CAD-only modeling/presentation stays in CAD.
Coordinates centre on the playing area, and printable models use assembly coordinates.
Each printable object has one owning generator; assembly imports it instead of redefining
it. The PCB proxy is a render stand-in, not the electrical/placement source of truth.

Coordinate populated PCB heights/keepouts with hardware engineer and manufacturing
constraints with manufacturing engineer. Hall-to-magnet distance, LED-to-plate spacing
and material/finish choices need evidence, not attractive renders. Do not change the
shared stack, PCB footprint positions or connectors without an agreed interface handoff.
Do not invent an alternate per-square enclosure or assume a desktop printer can fit the
current two large parts. Presentation materials do not specify purchased materials.

## Evidence and stopping point

Run assigned dimension/fast tests first, then coordinate `hardware/cad` generation with
QA. Check manifold/positive-volume meshes, scale, bounding boxes, assembly alignment,
clearance/tolerance calculations and generated views. Never hand-edit `.blend`/PNG
outputs or silently weaken validation. Report source paths, dimensions changed, commands,
artifacts and required real print/fit/optical measurements. Printable geometry is not
proof of fit, diffusion or Hall detection on a manufactured board. Stop for missing
manufacturing inputs or cross-domain conflicts and report to the lead.

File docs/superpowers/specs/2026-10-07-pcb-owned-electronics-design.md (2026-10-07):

# Shared specifications and PCB-dependent CAD generation

## Agreed direction

Keep readable shared supplier dimensions, named mounting interfaces and layout
values where both PCB and CAD need them. Removing shared definitions would make
ordinary access to these values harder without eliminating the need to author
them. Do not infer holes, contact positions or display areas from Blender meshes.

The main PCB, including its substrate, copper, holes, artwork and mounted
components, is rendered by KiCad into an importable GLB. CAD consumes that
checked export rather than building a second representation. Shared specifications
remain the source for enclosure fits and off-board assembly geometry.

## Scope

The existing PCB export/import pipeline already provides this model dependency.
Preserve it and simplify its orchestration:

- Keep the existing component-per-file structure and shared contracts.
- Keep the native KiCad model and portable component snapshot as a coherent,
  validated input bundle to CAD.
- Run PCB review before CAD in one CI job and the same workspace. Retain
  separate PCB and CAD artifacts, uploading only successfully generated output.
- Reuse the reviewed PCB bundle; standalone CAD refreshes it only if missing,
  stale or damaged. PCB failure prevents Blender execution and preserves
  previously published CAD output.
- Remove the unnecessary callback wrapper around CAD's export preparation.
- Correct documentation that overstates the current PCB ownership boundary.

Moving all off-board geometry into PCB or deleting the shared catalog is outside
this smaller change. Off-board geometry builders are not duplicates of the
main-PCB meshes; retain them until a concrete simplification justifies moving
individual parts. Do not add a new assembly schema solely to relocate them.

## Verification

Exercise checked-export reuse, missing/stale/damaged export refresh, interrupted
bundle copying and PCB failure before Blender. Run focused CAD checks and the
full local PCB-to-CAD generation sequence. Verify native DRC, component import
coverage, CAD fit checks and artifact provenance. Inspect regenerated assembly
renders. Validate CI workflow syntax and step order locally; GitHub scheduling
and execution require an actual workflow run.

All changes remain unstaged. Automated fit checks do not establish physical
manufacturing validation.

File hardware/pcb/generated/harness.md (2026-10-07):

# Harness wiring

Generated from `hardware/shared/electronics/harness.py`; do not edit.
Cavity numbers are JST's: cavity k mates header circuit k.

## Power entry

| Header | Cavity | Net | Wire | Far end | Terminal | Attach |
|---|---|---|---|---|---|---|
| J4 | 1 | DC_IN | red 18 AWG 200 mm | Switchcraft 722A | CENTER PIN | solder lug |
| J4 | 2 | GND | black 18 AWG 200 mm | Switchcraft 722A | SLEEVE | solder lug |
| J4 | 3 | DC_FUSED | orange 18 AWG 200 mm | E-Switch RA11131100 | either tab | FASTON 2-520275-2 |
| J4 | 4 | RUN | white 18 AWG 200 mm | E-Switch RA11131100 | other tab | FASTON 2-520275-2 |

- 1 JST VHR-4N: 4-pin VH receptacle housing for the power harness (bought: each)
- 4 JST SVH-21T-P1.1: VH crimp contact, AWG 22-18, insulation 1.7-3.0 mm (bought: each)
- 2 TE Connectivity 2-520275-2: FASTON .187 insulated receptacle, 22-18 AWG (bought: each)
- 1 x 200 mm Alpha Wire 3055 RD005: 18 AWG UL1007 wire, red (bought: 100 ft spool)
- 1 x 200 mm Alpha Wire 3055 BK005: 18 AWG UL1007 wire, black (bought: 100 ft spool)
- 1 x 200 mm Alpha Wire 3055 OR005: 18 AWG UL1007 wire, orange (bought: 100 ft spool)
- 1 x 200 mm Alpha Wire 3055 WH005: 18 AWG UL1007 wire, white (bought: 100 ft spool)

## OLED

| Header | Cavity | Net | Wire | Far end | Terminal | Attach |
|---|---|---|---|---|---|---|
| J2 | 1 | GND | black 28 AWG 180 mm | Qdtech / LCDWIKI MC242GW | GND | solder to pad |
| J2 | 2 | +3V3 | red 28 AWG 180 mm | Qdtech / LCDWIKI MC242GW | VCC | solder to pad |
| J2 | 3 | I2C_SCL | yellow 28 AWG 180 mm | Qdtech / LCDWIKI MC242GW | SCL | solder to pad |
| J2 | 4 | I2C_SDA | blue 28 AWG 180 mm | Qdtech / LCDWIKI MC242GW | SDA | solder to pad |

- 1 JST SHR-04V-S-B: 4-pin SH receptacle housing for the OLED harness (bought: each)
- 4 JST SSH-003T-P0.2-H: SH crimp contact, AWG 32-28, insulation 0.4-0.8 mm (bought: each)
- 1 x 180 mm Alpha Wire 2842/7 BK005: 28 AWG PTFE wire, black (bought: 100 ft spool)
- 1 x 180 mm Alpha Wire 2842/7 RD005: 28 AWG PTFE wire, red (bought: 100 ft spool)
- 1 x 180 mm Alpha Wire 2842/7 YL005: 28 AWG PTFE wire, yellow (bought: 100 ft spool)
- 1 x 180 mm Alpha Wire 2842/7 BL005: 28 AWG PTFE wire, blue (bought: 100 ft spool)

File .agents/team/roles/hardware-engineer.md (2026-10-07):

# Hardware engineer — electronics and PCB

## Read before matching work

- `hardware/shared/README.md`, `hardware/pcb/README.md`.
- `docs/hardware.md`, `docs/power.md`, `docs/host.md` for circuit/power/acquisition changes.
- Exact approved-part datasheets from `hardware/shared/components.py`; verify claims in
  those sources and current code. Historical prose can be stale.

## Scope and boundaries

Own assigned electrical design: approved components and typed pins, native `pcbnew`
footprints/connectivity, Hall-bank address straps and square mapping, I2C pull-ups and
bus loading, SPI/LED level shifting and chain order, OLED/buttons, power protection,
current/thermal margins, track/via/copper rules, decoupling and test access.
The Pi Zero 2 W is the sole processor; do not invent a microcontroller or sensor IRQ.
Hall acquisition is polled across eight TCA9554 banks. Check exact parts/mappings in
shared code rather than copying numbers from documentation.

Author `hardware/shared/{components,electronics,hall_banks,wiring}` and
`hardware/pcb/board/` only as assigned. Native board pads/nets are the electrical
source, not a parallel schematic model; schematic/netlist/BOM are derived output.
Coordinate shared dimensions with mechanical engineer and hand-maintained Pi pin
identities/acquisition behavior with firmware engineer. Do not edit their files or
shared contracts without explicit file ownership from the lead.

## Evidence and stopping point

Run assigned shared checks and PCB `check`/`review` recipes; coordinate heavy generation
with QA. Trace changed nets/pins and inspect ERC/DRC plus focused SPICE outcomes, including
startup, approved/full-white load, fault cases and logic thresholds where relevant.
Report datasheet passages, assumptions, calculations, source paths, changed interfaces,
commands and remaining bench measurements. A schematic that passes checks is not proof
of power safety, Hall/magnet margin or a working physical prototype. Never fabricate
measurements, bypass `board/evidence/`, release fabrication or order boards. Stop
for missing datasheet/physical evidence or cross-domain decisions; send one report to lead.

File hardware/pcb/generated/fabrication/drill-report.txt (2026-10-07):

Drill report for chess-board.kicad_pcb
Created on 2026-10-07T17:00:07+0000

Copper Layer Stackup:
    =============================================================
    L1 :  F.Cu                      front
    L2 :  In1.Cu                    in1
    L3 :  In2.Cu                    in2
    L4 :  In3.Cu                    in3
    L5 :  In4.Cu                    in4
    L6 :  In5.Cu                    in5
    L7 :  In6.Cu                    in6
    L8 :  B.Cu                      back

Drill file 'chess-board-PTH.drl' contains
    plated through holes:
    =============================================================
    T1  0.400mm  0.0157"  (780 holes)
    T2  0.900mm  0.0354"  (4 holes)
    T3  1.000mm  0.0394"  (48 holes)
    T4  1.020mm  0.0402"  (40 holes)
    T5  1.650mm  0.0650"  (4 holes)

    Total plated holes count 876

Drill file 'chess-board-NPTH.drl' contains
    unplated through holes:
    =============================================================
    T1  3.400mm  0.1339"  (20 holes)

    Total unplated holes count 20

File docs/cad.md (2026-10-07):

# CAD

## Purpose

Record mechanical source conventions and reviewed design decisions.

## Known direction

Component definitions under `hardware/cad/components` and the composed
assembly under `hardware/cad/board` are source; the `.blend`
models they produce live in `hardware/cad/generated`. Manufacturing
exports will be derived later.

The single `hardware/cad/board/generate.py` entry point uses the CAD harness to
build, validate, save and render every model atomically. Run
`just --justfile hardware/cad/justfile check` for checks and regeneration. Board
and harness tests are separate, like PCB; no legacy project discovery is required.

## Printed parts

Revision A needed 129 prints to cover a board: 64 tile lids, 64 tile trays and a
tray to hold them. The enclosure uses one case, one plate and twelve separately printable button caps.

- **`components/printable/board_case.py`** produces `Printable_Board_Case`, 344 x 404 x 30 mm,
  an open tub. The PCB drops straight into a pocket (outline plus 0.5 mm per
  side), rests on a ledge under its edge and on 20 bosses, and the Raspberry Pi
  hangs underneath it, component side up, at the shared Pi transform
  (`pi_header_pin_xy`) that also places J1. The power jack and rocker are
  panel-mounted in the back wall and wired to J4 on the board's underside.
- **`components/printable/tile_plate.py`** produces `Printable_Tile_Plate`, 335 x 395 mm,
  covering the whole board: the checkerboard engraved over the playing area with
  a through-window over each LED and an 18 × 18 mm square ring channel around a retained 14 × 14 mm island above each sensor, and the control bezel (twelve button holes,
  the raised bezel for the larger display) over the strip. It rests on the case rim
  outboard of the PCB pocket.

The bezel belongs to the plate rather than the case so that the board can be
lowered in from above: with a fixed bezel, the button stems that pass through it
would stop the board going in.

`board/board.py` composes the assembly. The harness imports both exact owning
meshes and imports the checked KiCad `chess-board.glb` assembly, including its
substrate, mounting holes, copper, artwork and package-local STEP models. All 327 component placements are represented, along with the
host board and display. It does not recreate printable geometry or rely on stale
PCB position exports. CAD refreshes stale PCB exports automatically; source and
artifact fingerprints prevent mixing revisions. Component model fidelity is
recorded in `3d-models.json`; dimension-based envelopes remain simplified.

The case is deeper than it is wide by exactly the 60 mm control strip. Putting
the buttons and the display on a face-up strip at the front of the same PCB is
what keeps every component on one side of the board and avoids right-angle parts.

## Coordinates and the assembly datum

Coordinates are centred on the **playing area**, not the case, so square centres,
LED positions and Hall-sensor positions stay symmetric about the origin while the case
carries `CASE_CENTER_OFFSET_Y_MM`.

All printable parts are generated in **assembly coordinates**: the case floor at
z = 0, the plate occupying the top 3 mm. `board-assembly` therefore moves neither
of them. That is deliberate — if the plate ever stops meeting the case, it is a
real error in `hardware/shared/dimensions/` rather than a positioning mistake in a view, and
the render shows it.

## Shared measurements

Shared CAD measurements live in `hardware/shared/dimensions/`, grouped by
board, case, panel, and tile plate. The package validates itself on import. Among other things it checks that the internal stack
— floor, Pi cavity, board, gap, plate — sums exactly to the case height, that
the board fits its pocket and the ledge carries every edge however the board
floats, that every plate screw lands on the rim rather than over the PCB, that
button stems stand 0.5-2.0 mm proud of the bezel, that no
support boss collides with an LED or a Hall sensor, and that every control-panel feature
stays on the control strip.

All modeled physical dimensions use millimetres. Generators must consume those
values rather than repeating physical measurements locally. Run the file directly
to print the current scale summary:

```sh
PYTHONPATH=hardware python3 -m shared.dimensions
```

## Scale

The selected form factor is intentionally a compact electronic chessboard. It
does not claim tournament-size compliance. For context, the FIDE equipment
specification effective March 2026 recommends 50-60 mm squares:
<https://handbook.fide.com/chapter/ChessEquipmentWithoutElectronicComponenets032026>.

40 mm squares suit a set whose king base is 32 mm or less, which covers most
ordinary club sets. Measure before buying magnets.

## Printing

The two enclosure parts are larger than a desktop printer bed: the case spans
404 mm and the plate 395 mm, so they are quoted from an FDM print service.
The twelve button caps fit a desktop printer.
`REFERENCE_DESKTOP_BUILD_VOLUME_MM` exists to state that rather than to gate
anything, and the tests assert that neither enclosure part fits it. An edge margin is
reserved before testing whether a part fits.

The plate's underside is pocketed square by square, leaving ribs on the grid
lines. A 3 mm solid sheet 320 mm across is a lot of material to have quoted and a
warping risk; the pockets remove about a third of it and double as the clearance
over the Hall sensors.

## Validation

Pure Python tests run in CI without Blender. During local regeneration,
`harness/base/blender/validation.py` additionally rejects non-manifold or zero-volume FDM meshes
and checks each generated part's measured bounding box against its build
envelope.

Two Blender-specific traps are guarded in `harness/base/blender/modeling.py`, because both fail
silently rather than reporting an error:

- A **bevel radius** must be under half the box's thinnest dimension, or the
  bevel folds through itself and produces an invalid mesh. `rounded_box` refuses
  it. The studio floor had been quietly invalid for exactly this reason.
- Cutters batched into **one boolean operand must be disjoint**. Joining is mesh
  concatenation, not a union, so overlapping members give the exact solver a
  self-intersecting operand and it deletes the body outright. Crossing grid
  grooves, and a screw shaft with its own head recess, go in separate batches.

## TODO

Confirm clearances, wall thicknesses, orientation, material shrinkage, and bed
adhesion with calibrated test prints before producing manufacturing exports.

## Piece placement and visible controls

Each square has an 18 × 18 mm square ring channel, 0.8 mm deep relative to its
own surface, surrounding a 14 × 14 mm center island. The island remains at the
square's surface level, elevated relative to the channel floor. Solid 19.6 × 19.6 mm
underside supports preserve the floor above the Hall sensors. The shared interface
for future pieces is a square ring foot, 17.5 mm outside and 14.5 mm inside,
projecting 0.6 mm below the base. Pieces lift out freely without a mechanical latch.
Their magnet pockets and physical sensing margin remain to be designed and tested.

The LEDs are exposed by 4.6 mm square through-windows. The control strip is
lowered 1 mm. The D-pad is on the left, OK beside the centered display, function
buttons on the right and Reset separated from them. Shared button identities
supply PCB switch positions, CAD placement, render labels and GPIO assignments.

The 2.42-inch MC242GW screen is exposed through a raised bezel. The module's
carrier rests on four mounting ledges with blind screw pilots and four top access holes; screen, frame,
carrier holes and solder pads follow the supplier drawing. Omit the supplied
upright header and solder the four 180 mm harness wires directly to pins 1–4;
RES remains open for onboard power-on reset. Print tolerances, screws, cap
retention and real wire dressing still require a physical prototype.

The OLED mount uses four [M2.5 × 3 DIN 912 socket screws](https://www.newstarfastenings.com/en-gb/products/m25-x-3-socket-cap-screw-din-912-steel-129-self-finish),
with 4.5 mm heads and a 2 mm hex driver. The bezel's 5 mm access holes allow
installation from above. Calibrate/drill and tap the printed 2 mm pilots to M2.5
before installing the carrier; verify thread holding and screw-tip clearance on
a prototype. Screw models are not included in the electronics envelope render.

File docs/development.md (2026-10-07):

# Development

Use the development container for the pinned Rust, Ruff, Blender, KiCad 9, and
Just toolchains. From the repository root:

```sh
just check
```

Run `just --list` for repository-wide capabilities. Every application, crate,
and hardware domain owns a `justfile`; run one directly to see and invoke only
that package's capabilities:

```sh
just --justfile hardware/pcb/justfile --list
just --justfile hardware/pcb/justfile review
just --justfile crates/chess/justfile check
just --justfile apps/firmware/justfile image-check
```

The root `justfile` only composes these package-owned recipes. Implementation and
package policy stay beside the code they operate on.

## Hardware domains

`hardware/shared` contains tool-independent dimensions, component specifications,
and wiring. `hardware/cad` adapts the physical contract into Blender models.
`hardware/pcb` owns electrical connectivity, footprints, placement, routing, and
fabrication output. There is no separate schematic domain.

The PCB's reviewed sources are the typed assemblies composed by
`hardware/pcb/board/board.py` and the shared component catalog. Generation
validates every footprint and connection, then writes the expanded netlist,
BOM, native schematic, board, and review reports under `hardware/pcb/generated/`.
The PCB attaches component STEP models and exports its native board assembly as
`chess-board.glb`, with component metadata and checked provenance. CAD imports
that geometry rather than rebuilding the substrate or its mounted electronics.
Both domains still use readable `hardware/shared` dimensions and mappings for
mechanical interfaces and off-board parts.

`just generate` reviews and generates the PCB first, then generates CAD using
that exact export. Running CAD alone also checks the PCB dependency: a missing,
stale or altered export is regenerated before Blender starts. A PCB generation
failure stops CAD and preserves the previous CAD outputs.

Generated hardware artifacts remain under each domain's `generated/` directory.
The PCB composes typed components through its reusable harness, which renders
native `pcbnew` objects. Review runs harness/catalog checks and generation with
native ERC/DRC reports, routed connectivity and board pytest/SPICE checks.
Fabrication files are exported for review; manufacturing approval and physical
evidence remain pending, so fabrication release currently refuses. Firmware host pin declarations in `apps/firmware/src/hardware/pins/` are
hand-maintained, not generated by the PCB pipeline. The CAD
recipe creates an ignored fallback toolchain under `.cache/blender` outside the
container; Yocto owns its caches under `.cache/yocto`.

## CI

The `PR` workflow invokes package-local recipes for code quality, every Rust
package, hardware, and firmware, and runs the Bun-managed `.pi` typecheck and
test suite with its frozen lockfile. In addition to host tests and Yocto metadata
validation, `Firmware checks / AArch64 binary` performs a locked optimized build
and links the real firmware executable for the Pi architecture. Cargo follows the
firmware package's complete dependency graph automatically, including local
workspace crates, target-specific code, build scripts, and native linkage. The
resulting executable is retained as a seven-day workflow artifact. This takes a
small fraction of a Linux image build and runs alongside hardware checks. Branch
protection requires the `Required checks` job on this workflow.

Hardware uses one sequential `PCB → CAD` job in both PR and main CI. PCB review
(including the PR report when requested) runs before CAD in the same workspace;
CAD reuses its validated model without a second PCB generation. The workflow
retains separate `pcb-generated` and `cad-generated` artifacts and uploads each
only after its generation step succeeds.

Push `CI` on `main` runs the same Hardware, Quality, and Pi harness jobs without
the pull-request firmware checks. Full Yocto image builds are isolated in the
`Firmware` workflow. Every successful `main` CI run starts it as a sibling
workflow after the normal checks, and it also runs weekly to detect ecosystem
drift or manually against any selected branch with **Actions → Firmware → Run
workflow**. A `v*` tag calls the same build only after the complete tag CI graph
succeeds, and only that gated invocation may publish release assets. Locally, `just firmware-update-crates` regenerates the checked-in Yocto crate
metadata from `apps/firmware/yocto/Cargo.lock`, `just firmware-check` parses and
dry-runs the BitBake image graph, `just firmware-binary` builds the AArch64
application, and `just firmware` constructs the complete image.

The version-controlled Git hook and `.pre-commit-config.yaml` both invoke
`just precommit`, which excludes expensive CAD renders and PCB fabrication
output. The pre-commit configuration also checks the generated Yocto crate
metadata whenever its manifest, lockfile, or generated include changes; stale
metadata fails with the regeneration command.

## Reading hardware and build files

The devcontainer includes Justfile and SPICE editor support. Python uses the
container's `/usr/bin/python3`; the editor discovers board tests with pytest.
KiCad supplies `pcbnew`, `eeschema` and `gerbview` for native projects. Additional
readers are `gerbv` for Gerber/Excellon files, `pdfinfo`, `pdftotext` and `pdftoppm`
for schematic/datasheet PDFs, `jq` for reports, `rg` for searches and `batcat` for
highlighted terminal output. Rebuild the devcontainer to install these additions.

```sh
batcat justfile
jq '.electrical_checks' hardware/pcb/generated/manifest.json
pdfinfo hardware/pcb/generated/schematic.pdf
gerbv hardware/pcb/generated/fabrication/chess-board-F_Cu.gbr hardware/pcb/generated/fabrication/chess-board-Edge_Cuts.gbr
```

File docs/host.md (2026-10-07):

# Host

## Purpose

Describe the software that runs on the Raspberry Pi: how it reaches the hardware,
how the board joins a network, and what the player sees when something is wrong.

## One binary

The Pi is the only processor, so the whole product is one Rust program in
`apps/firmware`, built for `aarch64-unknown-linux-gnu`. The app also owns the
Yocto definition for its flashable Linux system.

It reaches the hardware through Linux character devices:

| Device | Carries |
|---|---|
| `/dev/i2c-1` | eight TCA9554 expanders at 0x20-0x27, the OLED at 0x3C |
| `/dev/spidev0.0` | the SK9822 LED chain, through the level buffer |
| `/dev/gpiochip0` | twelve panel buttons (unchanged GPIO wiring) |

Suggested crates: `linux-embedded-hal` over `i2cdev`, `spidev` and `gpiocdev`.
The standalone SSD1309 driver exists, but it is not connected to a physical I2C
adapter or the runtime yet; the TCA9554 acquisition worker is also pending. Note
that `rppal`, the obvious first choice for Pi peripherals in Rust, was retired by
its author in July 2025, so the maintained character-device crates are the better
foundation for new work.

`apps/firmware/src/hardware/pins/` contains hand-maintained, function-named `GPIO`
descriptors for every connected Raspberry Pi line. They record host identity,
allowed direction and active-low behavior so drivers do not duplicate board
knowledge. PCB-to-Rust generation was deliberately removed; coordinate changes
to these descriptors with `hardware/shared/wiring.py` and the native PCB host
connections.

The LED frame needs no library. An SK9822 frame is a start frame of zero bytes,
four bytes per LED — brightness, then blue, green, red — and an end frame. Start
SPI at about 2 MHz, which is already over a thousand frames per second.

## Reading the board

The D-PROTOTYPE board **polls** eight TCA9554DWRs. Their INT outputs are
explicitly no-connect, and Pi header pin 7 (GPIO4) is unused. There is no shared
sensor IRQ, IRQ pull-up, or IRQ test point.

At startup, and after any detected expander power loss, write Configuration
register **0x03 = 0xFF** (all eight pins inputs) and Polarity Inversion register
**0x02 = 0x00**. Read Input Port register **0x00** using a command write followed
by a repeated-start byte read. There is one 8-bit port, not two; Output Port
register 0x01 must not be used to acquire sensors. Do not apply a different
expander family's register map or enable outputs against the open-drain sensors.

Scan addresses 0x20–0x27 in order; map P0–P7 with the bank contract in
`hardware/shared/hall_banks.py` (four files by two ranks; left half P0–P3,
right half P4–P7). LOW means occupied. Eight sequential reads are **not an atomic
64-square capture**. Begin at 100 kHz I²C, aiming for a complete scan every
25 ms; this is a starting software target, not measured scheduling performance.
A command/read uses about 36 bus clocks, so eight banks take about 2.88 ms at
100 kHz, before Linux and OLED traffic. Serialize access with the OLED and retain
per-bank timestamps. Failed reads mean unknown/stale data, never an empty square;
report faults and reconcile the full board after recovery. A stuck-low target
can block the entire shared bus.

The DRV5032FC samples internally at 20 Hz typical (27–75 ms period). Faster
polling cannot recover unobserved magnetic transitions. Require stable readings
across successive complete scans before reporting a move, with the final
filter/latency chosen by prototype testing. This is magnetic/noise filtering,
not mechanical-contact debounce. Button debounce remains a separate GPIO concern.

Each TCA9554 input has a **100 kΩ typical** internal pull-up to 3.3 V; this is
not a precision or guaranteed maximum resistance. No external Hall pull-ups or
RC filters are fitted. As an illustrative lumped estimate, 100 kΩ and 50 pF give
5 µs RC and about 6 µs to 0.7 VCC. Actual trace/input capacitance, leakage,
weak-pull-up variation, slow edges, and LED-coupled noise need measurement at the
furthest channels; a typical estimate is not a worst-case guarantee. Keep the
DRV5032FC 3.3 V open-drain output and local 100 nF bypassing.

The board has no SDA/SCL pull-ups (R1/R2 removed). The Pi's approximately
1.8 kΩ to 3.3 V operates in parallel with the approved MC242GW's documented
4.7 kΩ per line, giving 1.30 kΩ nominal. Verify the delivered module's resistors
before fitting and measure the complete populated bus. The capacitance estimate
now implies roughly 268 ns SDA rise time, but does not qualify 400 kHz operation;
retain the Pi's default 100 kHz (see [bus assumptions](hardware.md#buses-and-led-lines-s5)).
The retained stackup and local Hall routes do not prove signal integrity.

These are the contract for future hardware workers, not an implemented driver
or evidence of physical operation.

## Joining a WiFi network

WPS is not an option. Raspberry Pi OS has used NetworkManager since Bookworm,
NetworkManager has no client-side WPS enrollment, and WPA3 dropped WPS entirely.

Use access-point provisioning instead. On boot with no known network:

1. Raise a NetworkManager hotspot on `wlan0` with SSID `chess-XXXX`. The
   firmware uses the typed `nmrs` D-Bus API rather than shelling out to `nmcli`.
   NetworkManager's shared mode uses `dnsmasq` for DHCP and DNS.
2. Advertise the portal with DHCP option 114, per RFC 8910, so phones open it
   automatically.
3. Serve a page listing scanned networks, take a passphrase, and ask
   NetworkManager to persist the client profile.
4. Drop the hotspot and join.

A single radio cannot be an access point and a client at the same time, so
provisioning is strictly sequential. The player types the passphrase on their own
phone keyboard, which is why the board needs no on-device text entry.

The firmware `connectivity` module implements the NetworkManager controller for
status, scanning, WPA-protected hotspot lifecycle, and joining a selected client
network. It does not yet serve the captive portal, advertise DHCP option 114, or
coordinate those operations with startup and menu transitions.

## What the player sees

The OLED shows boot state, the hotspot name during setup, the IP address once
joined, and error text. Being a graphical display it can also render a QR code for
the setup page, which a character LCD could not.

Twelve buttons, all the same part: five directions, OK, RESET, PASS and F1 to F5.
A long press on RESET forgets the network and re-enters setup. Remapping any of
them is a change here and nowhere else, because they are wired straight to GPIO
rather than through an expander.

The 64 board LEDs are a second status surface — a red sweep for a fault, an amber
pulse for no network — and are useful precisely when the display is the thing that
has failed.

## Staying alive

There is no second processor to notice a hung kernel. Enable the Pi's own SoC
watchdog through systemd's `RuntimeWatchdogSec`. If LED animation ever looks
uneven, put the render thread on `SCHED_FIFO`; because the LED protocol is
clocked, scheduler jitter makes a frame late rather than corrupt.

## TODO

The systemd-supervised process, Yocto packaging, display driver, button input,
and NetworkManager control layer exist. LED output, Hall-sensor acquisition, the
captive provisioning portal, runtime connectivity coordination, and game
coordination are not implemented yet.

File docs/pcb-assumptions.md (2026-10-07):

# PCB engineering assumptions

These retained assumptions need reassessment against the current board. They are not validation evidence or fabrication approval. No prototype measurements are recorded.

## PTH copper rings

0.4 mm annulus (rules.THT_ANNULAR_RING_MM) on JST VH (J4), TL1105, Sullins and Rubycon pads: their drawings give holes only

## CAP_560U drill

0.9 mm: Rubycon ZLJ lead φ0.6 plus the repository's 0.3 mm THT allowance; no recommended hole is published

## OLED harness

J2 pins GND/3V3/SCL/SDA are soldered to MC242GW pins 1–4; optional RES is left open for onboard RC reset. The approved module supports 3.3 V per its supplier specification; omit its upright header.

## Jack/plug fit

Switchcraft 722A split Ø0.080 in centre pin is made for the 5.5 x 2.1 plug (EDG41 p134: S760, bore 2.03-2.13; plf6: pin .075-.077 in, insertion <= 3 lb, withdrawal >= 4 oz, contact <= 0.01 ohm initial, 0.02 ohm after humidity and durability); the GST18A05-P1J plug itself is not dimensioned on file; bench fit/retention/contact check

## J4 back offset

B4PS-VH body taken to start 1.0 mm behind the hole row; JST VH p3/p4 do not dimension it

## J2 circuit 1

SH side-entry land p1 has no circuit-1 mark; pin 1 at -X with the tabs at -Y is inferred from the p2 top view

## Harness parts

18 AWG wire (Alpha Wire 3055, four colour suffixes), 28 AWG PTFE wire (Alpha Wire 2842/7, 0.69 mm OD for the SSH contact, four colours) and TE 2-520275-2 FASTON (0.81 mm tab) are from distributor listings; manufacturing confirms the MPNs (the RA1 tab is 4.80 x 0.80 mm, E-Switch RA1 catalog drawing 11/2/2022, which the 0.81 mm FASTON fits)

## Pi Wi-Fi

Pi Zero 2 W PCB antenna (inferred, board x 118..138.5, y -54.5..-48.5) sits 11 mm under the full-plane 8-layer board in a printed case; no copper window (the rank-3 LED chain crosses that area); bench: hotspot RSSI/throughput at 1/3/10 m, case closed vs open

## MLCC lands

the 0603 MLCCs (100 nF, 10 nF, 1 nF, 1 uF) are Yageo class DA, 1.6 +-0.1 x 0.8 +-0.1 (CC X7R V.18 Table 3), matching the Murata ±0.10 lands; CAP_10U (0805 X5R) uses the 2.0x1.25 ±0.20 land, its Yageo X5R thickness class not read (sheet not obtained)

## Pi GPIO pull-ups

panel buttons rely on the Pi's internal pull-up, requested by firmware (apps/firmware/src/hardware/linux_gpio.rs Bias::PullUp); no board resistor

## GST18A05 output

GST18A-SPEC 2026-04-03 gives 5 V +-5 %, 80 mV p-p ripple, 3 A rated, overload 110-150 % hiccup, OVP 110-140 %, 16 AWG 1.2 m cord; bench: no-load and 2 A output voltage of the supplied unit (the board retains its 2 A budget)

## eFuse model

U74 (TPS259474ARPWR) is simulated from SLVSFC9C tables, no vendor model [BEH], with OVLO hysteresis and separate EN/OVLO thresholds, start-up limiting at ILIM, the ITIMER breaker (C143 1 nF: 1.286-1.741 V x 0.9-1.1 nF / 1.2-2.5 uA = 0.46-1.6 ms), the fast trip at ISC (2.01 x ILIM, typical only: no limits published) into limiting, and the 110 ms auto-retry; which branch a 4 A overload takes (fast trip, or the breaker) depends on that unpublished ISC spread and tSC is specified only above 3 x ILIM, so both branches are tested and bounded; thermal shutdown is not simulated (no transient thermal impedance published), so how long U74 limits before TSD is a bench item; reversed plug: 5.25 V / 604k = 8.7 uA per pin with an ideal clamp (< 10 uA, 8.2), the simulated figure uses a generic pin clamp; bench: scope inrush at hot plug and switch-on, OVLO trip with a lab supply, reversed plug, breaker trip at full white

## LED power-up state

SK9822-A Rev 01 p3 says 'default on electric lights'; distributors say no illumination at power-on. LED_5V stays off until LED_EN (S6), but if the chain wakes lit, enabling it pulls about 4 A: U74 either fast-trips and limits at 1.8 A (+5V about 3 V) or passes it until its breaker opens about 1.6 ms later (+5V then decays) [BEH], both before U5 can clock a blank frame (U75 holds U5 off until LED_5V is up, S6b H6): the Pi resets, R14 turns the rail off, the Pi reboots and enables again, a boot loop. PRE-ORDER bench test, before any LED purchase for assembly: a loose SK9822-A on a current-limited lab supply, DI and CI held low through 10 kOhm as on the board (S6d; the SK9822-A gives no input leakage, and 10 kOhm keeps DI/CI under 0.3 V for up to 30 uA of U5 plus U6 leakage, U5's IOZ being 2.5 uA max), VDD ramped 0 -> 5 V twenty times with no clock or data; pass = no LED lights and each LED draws < 5 mA before its first frame; then, on the board, enable an uninitialised chain and scope +5V, LED_5V and U74 current

## Host and logic current

+5V carries the Pi plus logic as 0.45 A: the Pi Zero 2 W's 'typical bare-board active' 350 mA (Raspberry Pi power-supplies documentation; no maximum is published) plus a 100 mA allowance for the OLED, U5, U75, the eight TCA9554 and the 64 DRV5032, not a datasheet sum; Pi peaks above typical (CPU load, Wi-Fi) are not covered; bench: board input current with LEDs off, idle and at full CPU load with Wi-Fi

## OVLO window

OVLO trips at 5.34-5.66 V (604k/169k 0.1 %, VOV(R) 1.183-1.223 V, +-0.1 uA) and restarts below 4.85-5.17 V (VOV(F)); C144 10 nF stops plug-in rings tripping it (without it a +5 % supply locks out at the low corner [BEH]); an overshoot above 5.34 V for about 1 ms or more that settles above 4.85 V still locks out until replugged; a supply failing into 5.5-5.66 V stays on and stresses the LEDs (VDD abs max 5.5 V); after any trip a supply at +5 % never restarts and 5.0 V restarts only at the high VOV(F) corner [BEH], so the product must be unplugged and replugged after an over-voltage event; bench: trip/restart points, plug-in with the real adapter

## LED supply window

SK9822-A Rev 01 lists the chip supply at 5.0 V typical, 5.3 V maximum (VDD range to 5.5 V): the PSU's +5 % (5.25 V) is inside it, but the OVLO trip (5.34-5.66 V) sits above 5.3 V and up to 0.16 V above the 5.5 V maximum at its latest corner; a supply between 5.3 V and the trip runs the LEDs beyond their recommended supply; bench: LED behaviour at 5.3-5.5 V

## OVLO filter

C144 delays OVLO: a running supply stepping to 6 V / 7 V trips after 1.72 / 0.65 ms; the rail peaks at 5.99 / 6.03 V and stays above 5.5 V for 10.5 / 10.0 ms with only the LEDs' static load (bulk capacitors hold it) [BEH]; D1 (VBR >= 13.3 V) does not clamp 6-7 V; bench: step a lab supply 5 -> 6 V under the idle board

## Fuse resistance

Littelfuse 451/453 gives F1's nominal cold resistance only (0.0367 ohm at 10 % of rated current, 25 C): the supply corner allows 1.5 x for tolerance and self-heating; bench: F1 voltage drop at 1 A

## Reversed 12 V adapter

D1 SMBJ12CA (user decision D2): a reversed 12 V adapter keeps the rail off (U74 IN -15 V rating, D1 off below 13.3 V) but pushes about 12 V / 604k = 20 uA into EN and OVLO with an ideal clamp, above TI's 10 uA (SLVSFC9C 8.2); surges clamp at VC 19.9 V (IN max 28 V); bench: reversed 12 V adapter, U74 still works afterwards

## EN at the surge clamp

at D1's 19.9 V clamp (SMBJ12CA VC at IPP) R6/R7 put U74 EN at 19.9 x 261k / 865k = 6.0 V, 0.5 V under its 6.5 V absolute maximum (SLVSFC9C 6.1); a clamp above about 21.5 V (a part swap, or a surge past IPP) would exceed it; bench: none, a part-change check

## LED moisture sensitivity

SK9822-A Rev 01 p1: MSL 5a (24 h floor life after opening the dry pack, then bake per J-STD-033); 64 LEDs on one panel make floor life an assembly constraint; U74 TPS259474ARPWR is MSL 2; the assembler confirms dry-pack handling and bake

## Cord inductance

supply cord and harness loop 0.5-1.5 uH (parallel-wire estimate about 0.8 uH for the 1 m UL2468 16 AWG cord; no cord drawing on file); bench: scope DC_FUSED at plug-in

## Rocker dry circuit

E-Switch RA1 (11.3.2022) rates RA11131100 at 10 A 125 VAC with 30 mOhm contact resistance max but gives no minimum switching current or dry-circuit rating: the rocker switches DC_FUSED onto RUN with a 1 kOhm wetting load (about 5 mA, 28 mW at 5.25 V); bench: RUN voltage and contact resistance over repeated switching

## U74 fine-pitch DRC

Lead-approved scoped rule (generated chess-board.kicad_dru): 0.16 mm clearance and 0.20 mm tracks only for U74 pads and escape copper inside its courtyard (RPW0010A 0.2 mm pad gaps), board 0.30/0.31 elsewhere; above PCBWay's 1 oz outer 5/6 mil (rules.PCBWAY_MIN_*); fab confirms at order

## Pi low voltage

Worst corner (PSU -5 %, end-of-life contacts, 70 C, fuse 1.5 x, Q1 hot) gives 4.525 V at the Pi header and 4.518 V at the farthest LED (Q1 drops 6.5 mV) [BEH]: SK9822/AHCT125 4.5 V met, the 4.63 V Pi warning level (not detected on the Zero range) not; bench: vcgencmd get_throttled with a low supply at the approved LED cap

## SK9822 input levels

Opsco SK9822-A Rev 01 gives no VIH/VIL: SPICE uses CMOS 0.7/0.3 x VDD for the AHCT125-driven data and clock; bench: chain test at the SPI clock

## Stackup

PCBWay 8-layer regular 1.6 mm (1 oz, 2116/7628 prepreg, Dk 4.45-4.74) from the fab's published table, +10 % capacitance: I2C load and LED line impedance (spice/bus_lines.py); fab confirms the stackup at order

## OLED pull-ups

The Pi's 1.8 kΩ and MC242GW's documented 4.7 kΩ (R2/R3 on its supplier schematic) give 1.30 kΩ nominal and 2.23 mA at 0.4 V; PCB R1/R2 remain omitted. Module input 10 pF and harness 50 pF/m remain estimates. Verify the delivered variant's resistors before fitting, then measure populated bus rise time and low voltage at the retained 100 kHz setting.

## LED line drivers

AHCT125 output 75/43 Ohm (SCLS264R VOH/VOL slopes) and 1-3 ns edges (not specified); SK9822 input 5 pF, output 25-100 Ohm with 1-3 ns edges (not in the Opsco sheet; R10-R12 terminate the In4 rank-turn data hops for that range); bench: scope U6 CKI/SDI and LED_D16 at the SPI clock

## Via plating

0.018 mm hole-wall copper (PCBWay standard 18-25 um, per the manufacturing review) for via ampacity; the fab's plating certificate confirms at order

## CAD CASE_ROCKER_BAY_DEPTH_MM

Rocker body and tabs reach 18.5 +/- 1.0 mm behind the panel (E-Switch RA1 sheet p2); the two TE 2-520275-2 receptacles and wire exit are not drawn. 50.5 mm reserved.

## CAD CASE_JACK_BAY_DEPTH_MM

722A body and lugs reach 15.3 mm behind the panel (drawing 20.8 - 5.46); 30 mm reserved for the soldered 18 AWG wires and their bend.

## CAD PI_SD_SOCKET_ON_PI_MM

microSD socket centre measured from the rendered RP-008358-DS-1 view; the drawing does not dimension it.

## CAD PI_SD_SOCKET_HEIGHT_MM

microSD socket height on the Pi Zero 2 W assumed (1.4 mm); sets the slot height.

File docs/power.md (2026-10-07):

# Power

## Purpose

Describe how the board is powered and where the current goes.

## No conversion on the board

The board keeps a 2 A operating budget and fuse rating.
A MEAN WELL GST18A05-P1J 5 V 3 A regulated supply feeds a Switchcraft 722A panel
jack in the case's rear wall, and that is the rail. There is no buck converter, no
inductor, no USB power negotiation and no battery. The 3.3 V the expanders and the
display need comes off the Raspberry Pi's own header.

The power path is a harness plus an on-board eFuse. Four wires join the panel jack
and the panel rocker (E-Switch RA11131100, also in the rear wall) to J4, a JST
B4PS-VH header on the board's bottom side (generated
[harness table](../hardware/pcb/generated/harness.md)):

| J4 circuit | Net | Goes to |
|---|---|---|
| 1 | `DC_IN` | jack centre pin, then F1 on the board |
| 2 | `GND` | jack sleeve |
| 3 | `DC_FUSED` | rocker, after F1 |
| 4 | `RUN` | rocker, other tab: the eFuse enable signal |

On the board: `DC_IN` goes through F1 (Littelfuse 0453002.MR, 2 A very fast-acting
surface-mount fuse, kept as the last-resort fuse) to `DC_FUSED`, which feeds the
TI TPS259474ARPWR eFuse (U74); its output is the `+5V` plane. D1, an SMBJ12CA
bidirectional TVS, sits on `DC_FUSED`. **The rocker no longer carries load current**:
it connects `DC_FUSED` to `RUN`, which enables the eFuse through a divider, and a
1 kΩ load (R8, about 5 mA) keeps the contacts wetted. Bulk storage is two Rubycon
560 µF electrolytics (C1, C140) on the bottom side plus a 10 µF ceramic (C2) next to
J4; each IC and LED has its own 100 nF capacitor.

The 64 LEDs do not hang directly on `+5V`: they run from a separate `LED_5V` plane
(inner layer 6), switched from `+5V` by a P-channel MOSFET (Q1, Vishay Si4403DDY),
so the LED rail can be off while the Pi boots. See "LED rail switch" below.

## Protection

Figures are from SPICE of the routed board at worst-case corners with a behavioural
eFuse built from datasheet tables (no vendor model), plus datasheet values; they are
not measurements.

- **Inrush and current limit:** the eFuse's dVdt capacitor sets a slow start; a
  hot-plug uses 0.0034 A²s, 0.64 % of the fuse's 0.530 A²s melting I²t (the usual rule
  is under 20 %). Above 1.80-2.20 A (ILIM) the eFuse's circuit breaker opens after its 0.46-1.6 ms
  fault timer (C143, 1 nF) and auto-retries 110 ms later; above about twice ILIM it trips
  at once and then limits at ILIM; during start-up it limits at ILIM (datasheet SLVSFC9C
  7.3.5, simulated with a behavioural model).
- **Over-voltage lockout (OVLO):** the output is cut above 5.342-5.663 V (restart
  4.854-5.173 V), set by a 604 kΩ/169 kΩ divider with a 10 nF filter (C144) so that
  a hot-plug ring on the cord does not lock the board out. TI requires divider
  resistors of at least 350 kΩ on input-referred pins for the reverse-polarity
  protection to hold. A 12 V adapter trips in about 1.04 ms with the rail at 0.36 V; 6 V,
  7 V and 12 V wrong adapters are refused safely at every corner (rail 0, the TVS stays
  off). The cut-off **latches**: after any over-voltage event, unplug and replug the
  supply; returning to 5.25 V does not restart it, and 5.0 V restarts only at one
  corner.
- **Surge clamp:** at the SMBJ12CA's clamp voltage the eFuse enable pin keeps 0.5 V of
  margin to its limit.
- **Reverse polarity:** the eFuse input is rated to -15 V; a reversed 5.25 V plug leaves
  the rail at 0 V, and the TVS does not conduct. **Avoid reversed 12 V adapters**: the
  model puts about 20 µA into the eFuse's enable and over-voltage pins, above TI's 10 µA
  limit for the reverse-polarity protection (an assumption with a test bound, not a
  closed risk).
- **Residual risks (assumptions, not closed):**
  - The window's top corner (5.663 V) is above the SK9822-A's 5.5 V absolute maximum
    and its 5.3 V recommended maximum, so a supply failing into 5.5-5.66 V stays on.
    A 5.25 V supply (the GST18A05's +5 % limit) is inside 5.3 V.
  - A supply that steps up to 6-7 V while running trips after about 0.7-1.7 ms, but
    the bulk capacitors hold the rail above 5.5 V for about 10 ms, with a peak of about
    6 V on the LEDs. D1 (SMBJ12CA, breakdown 13.3-14.7 V) does not clamp at 6-7 V.
- **Acceptance criterion:** the rail must stay at or above 4.5 V (the SK9822 and
  AHCT125 minimum) at the worst corner: supply at -5 % (4.75 V), end-of-life contact
  resistance, fuse resistance at 1.5 x cold, 70 °C copper, Q1 at its hot maximum
  resistance, the approved LED load at 18 mA per channel. The model gives 4.518 V at
  the LEDs and 4.525 V at the Pi header (Q1 drops 6.5 mV). The Pi's 4.63 V
  under-voltage level is **not met** at the worst corner; the
  Zero has no detector, so this is a bench check (`vcgencmd get_throttled` at the
  low corner), not a design pass.
- **Full white:** an unrestricted full-white frame draws 3.97 A including the host.
  Depending on the part's ILIM, the eFuse either trips at once and limits at 1.8-2.2 A
  (rail about 3 V) or passes the full load until its breaker opens within 1.6 ms; either
  way the Pi browns out and the fuse sees at most 0.025 A²s (4.7 % of its melting I²t).
  The approved load is below the 1.80 A minimum trip point.
- **Not modelled:** the eFuse vendor model and its thermal shutdown. Start-up limiting,
  the breaker, the fast trip and the auto-retry are simulated from the datasheet; how long
  it limits before thermal shutdown is a bench item.

## Current budget

| Load | Draw |
|---|---|
| 64 SK9822-A at unrestricted full white (budgeted at 18 mA per channel) | 3.97 A including the host (above the 2 A board budget and fuse) |
| Raspberry Pi Zero 2 W | about 0.4 A (included above) |
| Eight expanders and the buffer | small; not separately budgeted |

Full white is therefore not allowed. The prior electrical design used a global
brightness cap of 3/31 against the 2 A operating budget. The previous power,
ampacity and plane-mesh tests have been removed; these limits, routing dimensions
and voltage-drop calculations must be revalidated for the new routed board.
The generated project does not yet prove this power budget.

The protection analysis above covers supply-to-Pi voltage, inrush against the fuse's
I²t and the fault cases. Until the bench items below are done, the power path is not
qualified.

## LED rail switch

The LEDs are **off at boot**. A 100 kΩ pull-down holds `LED_EN` (BCM 26, header
pin 37) low, which keeps Q1 off. The 74AHCT125 buffer's outputs are high-impedance
until the LED rail is up: a TI SN74LVC1G97 (U75) combines the switch's gate and enable
signals into the buffer's output enables, so the buffer cannot drive the LED inputs
early, and it disables the outputs within about 1 µs when the rail switches off. While the buffer
is off, 10 kΩ pull-downs (R17/R18) hold the first LED's data and clock inputs low. Without
the switch a chain left in a lit state would draw about 4 A at power-up, which trips the
eFuse (immediately into 1.8-2.2 A limiting, or by the breaker within 1.6 ms). The firmware contract (`hardware/shared/electronics/sk9822.py`):

1. Set `LED_EN` high.
2. Stream **blank frames for at least 10 ms** (the blanking period). The buffer passes
   them to the LEDs about 2-3 ms after `LED_EN` rises (simulated 1.78-3.05 ms, with the
   LED rail at 4.6 V or more by then); frames sent earlier are dropped. Then send
   normal frames.
3. To switch off, send a blank frame, then take `LED_EN` low.

SPI clock at most 10 MHz. Frame: 32 zero bits, per LED `111` + 5-bit brightness then
Green, Red, Blue bytes (the SK9822-A order), then an end frame of `max(32, ceil(N/2))`
one bits for N LEDs. The simulation gives the LED rail a 10-90 % rise of about 0.95 ms
with a blanked chain, and a 0.56 A input peak. **A chain that powers up lit is not safe**:
in simulation `+5V` falls below the Pi's 4.63 V within about 3 ms, whichever way the
eFuse trips, which makes the board boot-loop. That residual is recorded as an assumption; bench it by enabling an
uninitialised chain. With the buffer held off, the LED data and clock inputs stay within
0.12 V of the LED rail in simulation (including the buffer's maximum off-state leakage;
limit 0.3 V above it) and within 25 mV of ground while the buffer is off.

## Never power the Pi from its own USB while it is fitted

Power the board from the panel jack only, and **never power the Pi through its own
micro-USB port while it is fitted to the board.** The Pi's 5 V is connected to the
board's `+5V` rail through the header, so USB power would feed all 64 LEDs and the rest
of the rail with no fuse or protection in the path, and would put two supplies in
opposition when the jack is also connected.

This is deliberately a documented constraint rather than a circuit. A TI LM66100
ideal diode between `+5V` and the Pi header would stop the back-feed but costs about
30-45 mV at the header, about twice the 15 mV margin above the 4.5 V floor. In the
closed case the Pi's micro-USB edge has no aperture (the case has only the SD slot,
jack and rocker), so Pi USB power is only possible with the case open, as on the bench. With the eFuse, reverse current to the jack side is also blocked.

## Bench items

The ordered bench checklist that covers these is [bring-up](bring-up.md).

Related signal-integrity items (I²C rise time, LED line edges) are in
[hardware](hardware.md#buses-and-led-lines-s5).

No automated check proves any of these; they stay in `ASSUMPTIONS`
(`docs/pcb-assumptions.md`) until measured:

- enabling `LED_EN` into an uninitialised (possibly lit) chain, and the blank-frame timing (10 ms blanking, 2-3 ms buffer delay);
- the real supply: actual output voltage and tolerance, plug-in overshoot and hiccup;
  measure it against the board's OVLO trip and restart points with the real adapter and
  a lab supply;
- the Pi's behaviour at the worst-corner rail (`vcgencmd get_throttled`);
- plug-in ring and a running over-voltage step reaching the LEDs;
- the eFuse's trip and retry with a lit chain or full white (simulated; bench step 5.5 and an override test), and its heating while limiting;
- U74 assembly (fine-pitch QFN, X-ray) and selective soldering of the bottom
  through-hole joints at the fab;
- the rocker switching about 5 mA of wetting current reliably, contact resistances,
  the jack's 2.0 mm centre pin mating with the GST18A05-P1J plug, and harness crimps and
  cavity order.

## Watchdog

There is no separate processor to notice a hung host. Use the Pi's own SoC
watchdog through systemd's `RuntimeWatchdogSec`, which costs no extra parts.

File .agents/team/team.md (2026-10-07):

# Chess engineering team

Read `AGENTS.md`, your role brief and the owning package documentation. Work in the
devcontainer. This is a physical chessboard driven by one Pi Linux process, with native
KiCad electrical design and Python-generated Blender mechanics—not a desktop study app.

## Roster and ownership

The default roster has eight roles. Availability is not a requirement to use every role:
small tasks should start only the needed agents. At most ten agents may run together,
leaving two concurrent slots for the six on-demand roles. The lead chooses those roles
for concrete outcomes; do not auto-evict workers, create per-domain/nested teams or raise
the cap without operator approval. Start a missing role with `python3 .agents/team/agents.py up <role> --no-attach`.

| Role | Responsibility | Normal authoring scope (only assigned files) |
| --- | --- | --- |
| lead | Requirements, interface decisions, integration and Git | Checkpoint, integration fixes |
| developer | Portable chess/menu/core/persistence/logger logic | `crates/` and callers agreed with firmware |
| firmware-engineer | Pi runtime, typed events, Linux device/network adapters | `apps/firmware/src/` and assigned tests |
| hardware-engineer | Circuit/power/pins, native PCB/connectivity/routing | `hardware/pcb/board/`, shared electrical contracts |
| mechanical-engineer | Enclosure/tile plate, tolerance/optical/assembly stack | `hardware/cad/`, shared dimensions |
| qa | Independent behavior/evidence verification | Reports; assigned validation execution |
| reviewer | Read-only correctness/contracts/regression review | Reports |
| pushback | Read-only challenge to architecture and physical assumptions | Reports |
| manufacturing-engineer (on demand) | DFM, sourcing, assembly/prototype/release evidence | Reports; explicitly assigned source/docs |
| test-engineer (on demand) | Test harnesses, negative cases, reproducible fixtures | Assigned test paths |
| devops-engineer (on demand) | Devcontainer, CI, toolchain, Yocto packaging | `.devcontainer/`, `.github/`, tooling, Yocto |
| pm (on demand) | Product acceptance and scope decisions | Reports |
| upgrade-reviewer (on demand) | Persisted data, contract and contributor upgrade risks | Reports |
| pr-maker (on demand) | Authorized Git/PR delivery using existing evidence | Explicitly handed-off Git paths |

These are responsibility boundaries, not blanket write permission. The lead assigns the
question/outcome, allowed files, acceptance check and stopping point. One writer per
file, one Git owner and one expensive-check owner. Reviewers/QA/pushback do not modify
implementation by default. Unassigned agents stay idle and send no status prompts.

## Interface changes

- Electronics → firmware: share net/pin identities, voltage/polarity, timing, Hall-bank
  addresses/mapping, LED order and brightness/power limits. Pi pin declarations are
  hand-maintained; coordinate both sides rather than inventing PCB-to-Rust generation.
- PCB → mechanics: share populated heights, keepouts, supports, holes, connector access
  and magnet/sensor/LED stack. Only agreed cross-domain measurements belong in
  `hardware/shared/dimensions.py`; tool behavior stays with its domain.
- Design → manufacturing: confirm exact approved parts, footprint/process compatibility,
  print/board tolerance and assembly/prototype acceptance. A render or clean DRC does
  not authorize a part substitution or fabrication.
- Runtime → image: coordinate required devices/kernel/packages/services between firmware
  and DevOps. A host/VM test, AArch64 link and Yocto image validate different boundaries.

For such a change, the lead identifies the affected peer, agrees the interface, assigns
one writer for each shared file, and includes the peer's evidence in review. Do not pass
broad ownership of `hardware/shared` to two engineers at once. Verify current code and
exact datasheets: historical documentation may contain obsolete counts or claims.

## Execution and evidence

Work in small slices: implement, focused test, report, read-only review, fix, then the
next slice. No fixed approval chain; use the perspectives relevant to the changed risk.
Never hand-edit generated hardware output, weaken checks or reproduce a failure by
resetting someone else's work. Generated PCB/CAD sets have one assigned producer.

Run focused package checks before combined validation. The lead grants one runner for
PCB `review`, CAD generation, Docker/QEMU E2E and Yocto tasks, then reuses the results.
Full PCB `release`, Yocto image builds, physical flashing, vendor uploads and purchasing
are separate authorized actions, not routine QA. Missing physical evidence remains a
blocker; never replace it with synthetic measurements or relaxed validation.

Every report labels its evidence: source/datasheet calculation, software unit test,
SPICE, mesh/render, Linux simulation, AArch64 linkage, Yocto metadata/image or actual
operator/bench observation. Record code/diff identity, exact inputs/commands, result and
untested limits. None of the automated categories proves physical electrical safety,
Hall/magnet margin, printed fit or a working manufactured board.

Write reports to the `Reports:` path in your brief as `<role>-<topic>.md`. Send the file
as one quoted argument; never paste arbitrary text into a shell command:

```sh
session=chess # replace with the session in your brief
report=target/agents/"$session"/reports/hardware-engineer-result.md
herdr --session "$session" agent prompt lead "$(cat -- "$report")"
```

Only lead talks to the user and updates `task.md`: objective, starting branch/preexisting
changes, interface decisions, owned files/check runner, current step, evidence and next
action (under 60 lines). Inspect the current diff before recovering a checkpoint or
reusing test-engineer fixtures. Reports/checkpoints are gitignored under
`target/agents/<session>`. Old evidence is a pointer to revalidate, not a current fact.

Herdr's sidebar owns status. Do not poll or wake models for progress. Send blockers once
with a concrete decision needed. Lead may inspect/re-brief a stalled pane. Do not answer
provider permission/trust dialogs on the user's behalf or silently enable bypass.
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

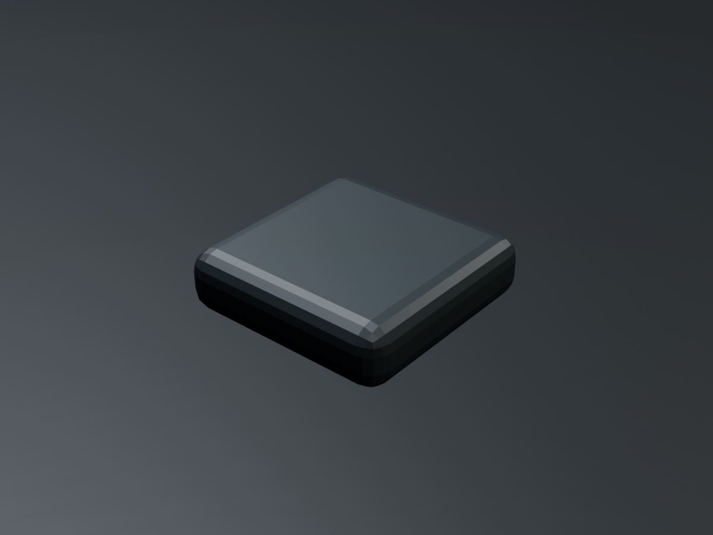
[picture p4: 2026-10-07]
hardware/cad/generated/button-cap-up.png

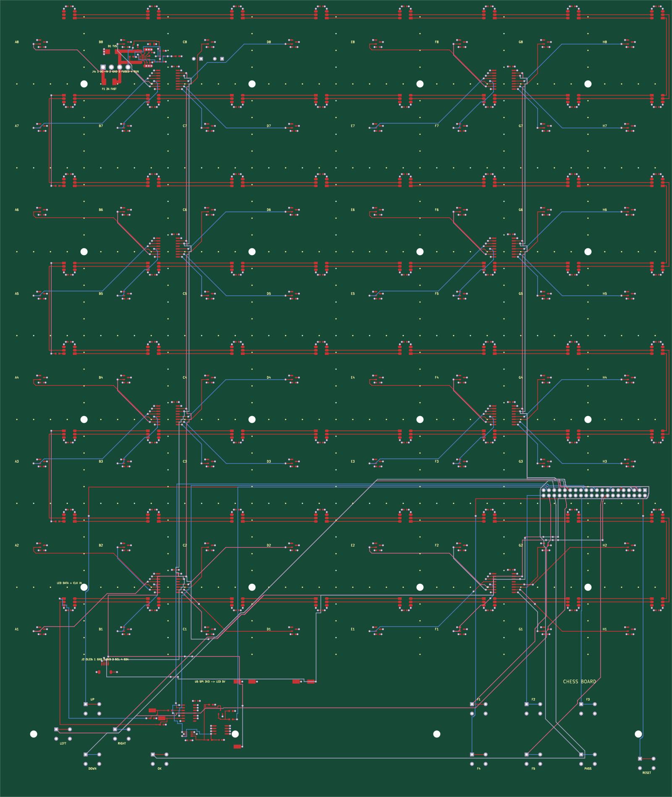
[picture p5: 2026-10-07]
hardware/pcb/generated/board-routing.png

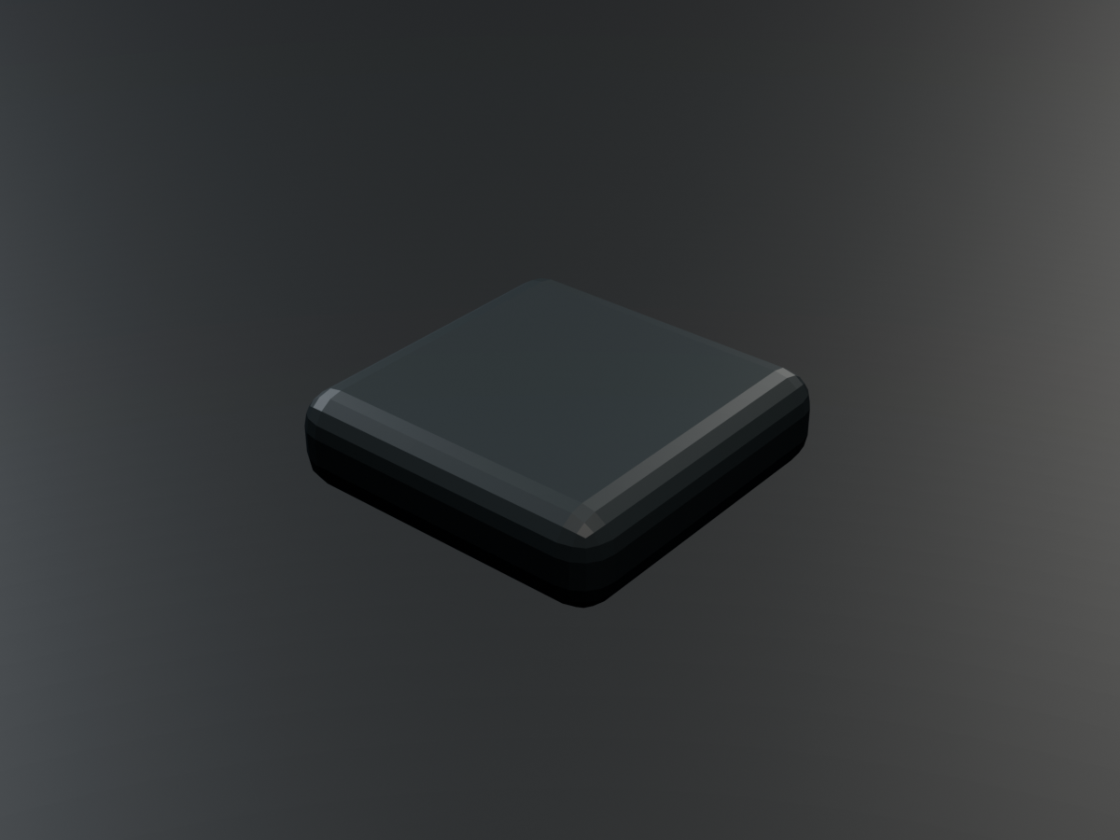
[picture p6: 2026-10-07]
hardware/cad/generated/button-cap-f2.png

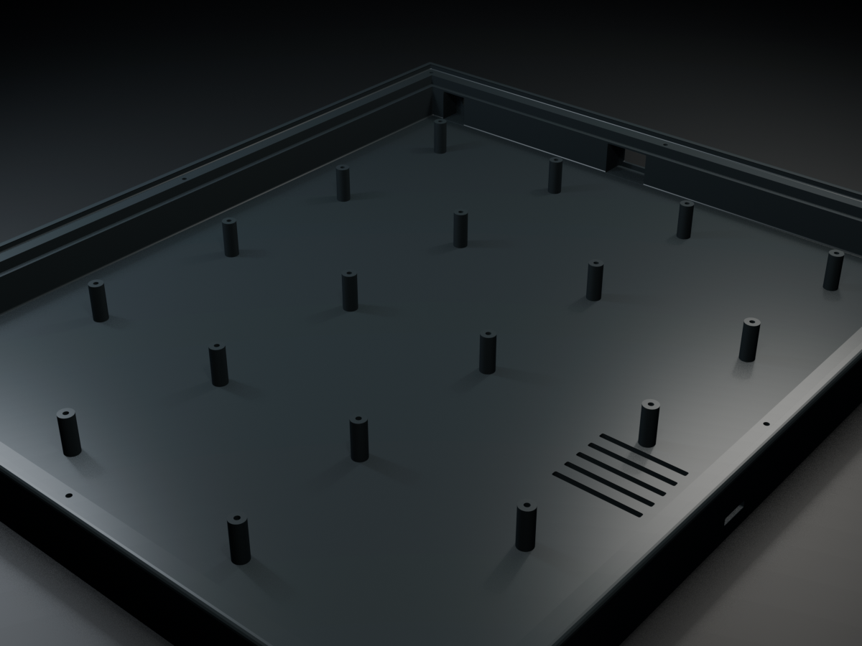
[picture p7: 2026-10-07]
hardware/cad/generated/board-case.png

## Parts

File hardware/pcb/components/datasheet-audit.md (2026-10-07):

# Datasheet availability audit

Checked on 2026-10-06 from the development container.

**All 49 approved purchasing products have URLs: 33 unique URLs passed; zero failed; zero missing.**
This includes 29 PCB definitions, 12 off-board products and eight wire spools.
Availability does not establish part identity, revision parity or physical correctness.

| Components | Document |
|---|---|
| FUSE_2A | [document](https://atta.szlcsc.com/upload/public/pdf/source/20171109/C48467_15102201734031103760.pdf) |
| OLED_MODULE | [document](https://cdn.shopify.com/s/files/1/1509/1638/files/0_96_Zoll_Display_Datenblatt_AZ-Delivery_Vertriebs_GmbH_241c4223-c03f-4530-a8c0-f9ef2575872f.pdf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) |
| POWER_SWITCH | [document](https://configured-product-images.s3.amazonaws.com/2D/specs/RA11131100.pdf) |
| TEST_POINT | [document](https://content.harwin.com/asset/e4e6a5e1-de35-4a2b-8b49-ff06562cba9d/DRG-02202-Technical-Drawing-Datasheet-S1751R-pdf.pdf) |
| PI_ZERO_2_W | [document](https://datasheets.raspberrypi.com/rpizero2/raspberry-pi-zero-2-w-product-brief.pdf) |
| BARREL_JACK | [document](https://docs.rs-online.com/33bc/0900766b8141ad6e.pdf) |
| TVS_12V0 | [document](https://docs.rs-online.com/72ea/0900766b814f6468.pdf) |
| MICRO_SD | [document](https://documents.sandisk.com/content/dam/asset-library/en_us/assets/public/sandisk/product/memory-cards/high-endurance-uhs-i-microsd/data-sheet-high-endurance-uhs-i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) |
| ROCKER_RECEPTACLE | [document](https://media.distrelec.com/Web/Downloads/_t/ds/2-520275-2_eng_tds.pdf) |
| OLED_HARNESS_WIRE_BLACK, OLED_HARNESS_WIRE_BLUE, OLED_HARNESS_WIRE_RED, OLED_HARNESS_WIRE_YELLOW | [document](https://www.alphawire.com/disteAPI/SpecPDF/DownloadProductSpecPdf?productPartNumber=2842%2F7) |
| POWER_HARNESS_WIRE_BLACK, POWER_HARNESS_WIRE_ORANGE, POWER_HARNESS_WIRE_RED, POWER_HARNESS_WIRE_WHITE | [document](https://www.alphawire.com/disteAPI/SpecPDF/DownloadProductSpecPdf?productPartNumber=3055) |
| BUTTON | [document](https://www.e-switch.com/wp-content/uploads/2022/06/TL1105.pdf) |
| LED_SWITCH_DRIVER | [document](https://www.farnell.com/datasheets/1596366.pdf) |
| OLED_HARNESS_CONTACT, OLED_HARNESS_HOUSING, OLED_HEADER | [document](https://www.jst-mfg.com/product/pdf/eng/eSH.pdf) |
| POWER_HARNESS_CONTACT, POWER_HARNESS_HOUSING, POWER_HEADER | [document](https://www.jst-mfg.com/product/pdf/eng/eVH.pdf) |
| POWER_SUPPLY | [document](https://www.meanwell.com/Upload/PDF/GST18A/GST18A-SPEC.PDF) |
| SK9822 | [document](https://www.rose-lighting.com/wp-content/uploads/sites/53/2020/05/SK9822-A-REV.01-EN-5050-RGB-27K-HZ-PWM-30M-bps-speed.pdf) |
| CAP_560U | [document](https://www.rubycon.co.jp/wp-content/uploads/catalog-aluminum/ZLJ.pdf) |
| PI_MALE_HEADER | [document](https://www.sullinscorp.com/catalogs/77_PAGE108-109_.100_MALE_HDR.pdf) |
| PI_ZERO_HEADER | [document](https://www.sullinscorp.com/pdfs/catalog.pdf) |
| HALL_SENSOR | [document](https://www.ti.com/lit/ds/symlink/drv5032.pdf) |
| AHCT125 | [document](https://www.ti.com/lit/ds/symlink/sn74ahct125.pdf) |
| LED_ENABLE_GATE | [document](https://www.ti.com/lit/ds/symlink/sn74lvc1g97.pdf) |
| TCA9554 | [document](https://www.ti.com/lit/ds/symlink/tca9554.pdf) |
| EFUSE | [document](https://www.ti.com/lit/ds/symlink/tps25947.pdf) |
| LED_SWITCH | [document](https://www.vishay.com/docs/70094/si4403ddy.pdf) |
| RES_100K, RES_10K, RES_1K, RES_1K65, RES_261K, RES_56 | [document](https://www.yageogroup.com/content/datasheet/asset/file/PYU-RC_GROUP_51_ROHS_L) |
| RES_169K_PRECISION, RES_604K_PRECISION | [document](https://www.yageogroup.com/content/datasheet/asset/file/PYU-RT_1-TO-0-01_ROHS_L) |
| CAP_1U | [document](https://www.yageogroup.com/download/specsheet/CC0603KRX7R8BB105) |
| CAP_1N | [document](https://www.yageogroup.com/download/specsheet/CC0603KRX7R9BB102) |
| CAP_10N | [document](https://www.yageogroup.com/download/specsheet/CC0603KRX7R9BB103) |
| CAP_100N | [document](https://www.yageogroup.com/download/specsheet/CC0603KRX7R9BB104) |
| CAP_10U | [document](https://www.yageogroup.com/download/specsheet/CC0805KKX5R6BB106) |

Manufacturer-authored documents are preferred. The fuse, TVS, MOSFET, barrel
jack and FASTON receptacle use distributor-hosted copies because the original
vendor endpoints block automated access or are unavailable. The accessible onsemi
copy is Rev. 6 and the TVS copy is dated 2016; existing engineering notes reference
newer revisions. Link availability does not resolve that revision review.

The approved supply was corrected, with user authorization, to GST18A05-P1J
(5 V, 3 A). Its documented voltage, ripple and cord corners now feed SPICE; the
board operating budget and fuse remain 2 A.

The OLED PDF describes 28x33 mm while the catalog records 27x27 mm; resolve
the module revision before changing geometry. E-Switch lists RA11131100 as
obsolete; its exact drawing remains linked, and purchasing needs a replacement
review before ordering. Capacitor lands still use the documented Murata land
assumption; adding exact Yageo product URLs does not close that assumption.

Re-run `just --justfile hardware/pcb/justfile datasheets`. The automatic gate
in [`harness/checks`](../harness/checks/README.md) rejects missing and failed URLs.

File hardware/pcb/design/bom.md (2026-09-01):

# Approved bill of materials

Generated from `hardware/shared/components.py` and `netlist.json`.
Every row names an exact manufacturer part number; substitutions require
updating the shared catalog and passing footprint/package validation.

| Qty | Manufacturer part number | Manufacturer | Description | Package | References |
|---:|---|---|---|---|---|
| 1 | `SN74AHCT125DR` | Texas Instruments | Quad 3.3 V to 5 V logic buffer | SOIC-14 1.27 mm | U5 |
| 1 | `PJ-102A` | Same Sky | 5.5x2.0 mm centre-positive DC jack | 5.5x2.0 mm THT | J3 |
| 12 | `TL1105SPF100QG` | E-Switch | 6 mm tactile switch, 9.5 mm actuator | 6x6 mm THT | SW1, SW2, SW3, SW4, SW5, SW6, SW7, SW8, SW9, SW10, SW11, SW12 |
| 1 | `10ZLJ1000M10X16` | Rubycon | 1000 uF 10 V low-ESR electrolytic | radial 10 mm | C1 |
| 133 | `CC0603KRX7R9BB104` | Yageo | 100 nF 50 V X7R MLCC | 0603 (1608 metric) | C3, C4, C5, C6, C7, C8, C9, C10, C11, C12, C13, C14, C15, C16, C17, C18, C19, C20, C21, C22, C23, C24, C25, C26, C27, C28, C29, C30, C31, C32, C33, C34, C35, C36, C37, C38, C39, C40, C41, C42, C43, C44, C45, C46, C47, C48, C49, C50, C51, C52, C53, C54, C55, C56, C57, C58, C59, C60, C61, C62, C63, C64, C65, C66, C67, C68, C69, C70, C71, C72, C73, C74, C75, C76, C77, C78, C79, C80, C81, C82, C83, C84, C85, C86, C87, C88, C89, C90, C91, C92, C93, C94, C95, C96, C97, C98, C99, C100, C101, C102, C103, C104, C105, C106, C107, C108, C109, C110, C111, C112, C113, C114, C115, C116, C117, C118, C119, C120, C121, C122, C123, C124, C125, C126, C127, C128, C129, C130, C131, C132, C133, C134, C135 |
| 1 | `CC0805KKX5R6BB106` | Yageo | 10 uF 10 V X5R MLCC | 0805 (2012 metric) | C2 |
| 1 | `0453005.MR` | Littelfuse | 5 A time-delay surface-mount fuse | 2410 fuse | F1 |
| 64 | `DRV5032FCDBZR` | Texas Instruments | 20 Hz omnipolar active-low Hall-effect sensor | SOT-23-3 | HS1, HS2, HS3, HS4, HS5, HS6, HS7, HS8, HS9, HS10, HS11, HS12, HS13, HS14, HS15, HS16, HS17, HS18, HS19, HS20, HS21, HS22, HS23, HS24, HS25, HS26, HS27, HS28, HS29, HS30, HS31, HS32, HS33, HS34, HS35, HS36, HS37, HS38, HS39, HS40, HS41, HS42, HS43, HS44, HS45, HS46, HS47, HS48, HS49, HS50, HS51, HS52, HS53, HS54, HS55, HS56, HS57, HS58, HS59, HS60, HS61, HS62, HS63, HS64 |
| 4 | `MCP23017-E/SO` | Microchip Technology | 16-bit I2C GPIO expander | SOIC-28W 1.27 mm | U1, U2, U3, U4 |
| 1 | `SDSQQNR-032G-GN6IA` | SanDisk | 32 GB high-endurance microSD card | microSD | — |
| 1 | `PPPC041LFBN-RC` | Sullins Connector Solutions | 1x4 OLED socket | 1x4 2.54 mm THT | J2 |
| 1 | `1.3inch OLED (A) 10444` | Waveshare | 1.3 inch 128x64 I2C OLED module | 35.5x33.5 mm module | — |
| 1 | `SC0510` | Raspberry Pi | Raspberry Pi Zero 2 W host | 65x30 mm module | — |
| 1 | `PPPC202LFBN-RC` | Sullins Connector Solutions | Raspberry Pi Zero 2 W 2x20 socket | 2x20 2.54 mm THT | J1 |
| 1 | `GST40A05-P1J` | MEAN WELL | 5 V 6 A regulated desktop supply | external PSU | — |
| 1 | `RA11131100` | E-Switch | PCB SPST rocker switch | SPST rocker THT | SW13 |
| 2 | `RC0603FR-074K7L` | Yageo | 4.7 kohm 0.1 W thick-film resistor | 0603 (1608 metric) | R1, R2 |
| 64 | `SK9822-EC20` | Opsco Optoelectronics | Clocked 5050 RGB LED | PLCC-6 5050 | U6, U7, U8, U9, U10, U11, U12, U13, U14, U15, U16, U17, U18, U19, U20, U21, U22, U23, U24, U25, U26, U27, U28, U29, U30, U31, U32, U33, U34, U35, U36, U37, U38, U39, U40, U41, U42, U43, U44, U45, U46, U47, U48, U49, U50, U51, U52, U53, U54, U55, U56, U57, U58, U59, U60, U61, U62, U63, U64, U65, U66, U67, U68, U69 |
| 4 | `S1751-46R` | Harwin | Low-profile surface-mount test point | SMD test point | TP1, TP2, TP3, TP4 |
| 1 | `SMBJ6.0A` | Littelfuse | 6 V unidirectional TVS diode | SMB (DO-214AA) | D1 |

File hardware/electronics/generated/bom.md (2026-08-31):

# Bill of materials

Generated by `hardware/electronics/core/bom.py`; do not edit by hand. Quantities are
counted from the symbols placed on each schematic, so this file and the
drawings always agree.

## Chess Smart Board - Single Board Electronics

`projects/board/generate.py` places 233 components.

### By function

| Qty | Value | Package | Description | References |
|----:|---|---|---|---|
| 64 | 100nF | disc 2.54 mm | Local LED decoupling capacitor | C8-C71 |
| 64 | REED NO | axial 14 mm | Normally-open through-hole reed switch | RS1-RS64 |
| 64 | SK9822 | PLCC-6 5050 | Clocked 5050 RGB LED | U6-U69 |
| 12 | TACT 6mm | 6x6 mm THT | Momentary panel button, 9.5 mm actuator | SW1-SW12 |
| 4 | 100nF | disc 2.54 mm | Expander decoupling capacitor | C3-C6 |
| 4 | DIP-28 socket | DIP-28 | Turned-pin socket; the chip drops in after assembly | SKT1-SKT4 |
| 4 | MCP23017-E/SP | PDIP-28 | 16-bit I2C port expander, one per board quadrant | U1-U4 |
| 2 | 4.7k | axial 1/4 W | I2C pull-up | R1, R2 |
| 1 | +5V | turret 1.6 mm THT | 5 V test point | TP1 |
| 1 | 1000uF 10V | radial 10 mm | LED rail bulk capacitor | C1 |
| 1 | 100nF | disc 2.54 mm | Buffer decoupling capacitor | C7 |
| 1 | 10uF 16V | radial 5 mm | Rail decoupling capacitor | C2 |
| 1 | 1x4 header | 1x4 2.54 mm THT | SSD1306 OLED module connector | J2 |
| 1 | 2x20 header | 2x20 2.54 mm THT | Raspberry Pi Zero 2 W GPIO socket | J1 |
| 1 | 5 A | 5x20 mm holder THT | Input over-current protection | F1 |
| 1 | DC 5.5x2.1 | 5.5x2.1 mm THT | 5 V DC input jack, centre positive | J3 |
| 1 | DIP-14 socket | DIP-14 | Turned-pin socket; the chip drops in after assembly | SKT5 |
| 1 | GND | turret 1.6 mm THT | Ground test point | TP2 |
| 1 | LED_CLK_5V | turret 1.6 mm THT | Buffered LED clock test point | TP4 |
| 1 | LED_DATA_5V | turret 1.6 mm THT | Buffered LED data test point | TP3 |
| 1 | P6KE6.8A | axial DO-15 | Input transient suppressor on the 5 V rail | D1 |
| 1 | POWER | SPST rocker THT | Latching power switch | SW13 |
| 1 | SN74AHCT125N | DIP-14 | Quad 5 V buffer accepts 3.3 V SPI clock and data | U5 |

### To order

| Qty | Part | Package |
|----:|---|---|
| 69 | 100nF | disc 2.54 mm |
| 64 | REED NO | axial 14 mm |
| 64 | SK9822 | PLCC-6 5050 |
| 12 | TACT 6mm | 6x6 mm THT |
| 4 | DIP-28 socket | DIP-28 |
| 4 | MCP23017-E/SP | PDIP-28 |
| 4 | Turret test point | turret 1.6 mm THT |
| 2 | 4.7k | axial 1/4 W |
| 1 | 1000uF 10V | radial 10 mm |
| 1 | 10uF 16V | radial 5 mm |
| 1 | 1x4 header | 1x4 2.54 mm THT |
| 1 | 2x20 header | 2x20 2.54 mm THT |
| 1 | 5 A | 5x20 mm holder THT |
| 1 | DC 5.5x2.1 | 5.5x2.1 mm THT |
| 1 | DIP-14 socket | DIP-14 |
| 1 | P6KE6.8A | axial DO-15 |
| 1 | POWER | SPST rocker THT |
| 1 | SN74AHCT125N | DIP-14 |

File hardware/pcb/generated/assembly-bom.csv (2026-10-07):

Quantity | Designators | Manufacturer | Manufacturer Part Number | Package | Type
12 | SW1, SW10, SW11, SW12, SW2, SW3, SW4, SW5, SW6, SW7, SW8, SW9 | E-Switch | TL1105CF100Q | 6x6 mm THT | Through-hole
7 | TP1, TP2, TP3, TP4, TP5, TP6, TP7 | Harwin | S1751-46R | SMD test point | SMD
1 | J4 | JST | B4PS-VH | VH 4P side entry THT | Through-hole
1 | J2 | JST | SM04B-SRSS-TB | SH 4P side entry SMD | SMD
1 | F1 | Littelfuse | 0453002.MR | 2410 fuse | SMD
1 | D1 | Littelfuse | SMBJ12CA | SMB (DO-214AA) | SMD
64 | U10, U11, U12, U13, U14, U15, U16, U17, U18, U19, U20, U21, U22, U23, U24, U25, U26, U27, U28, U29, U30, U31, U32, U33, U34, U35, U36, U37, U38, U39, U40, U41, U42, U43, U44, U45, U46, U47, U48, U49, U50, U51, U52, U53, U54, U55, U56, U57, U58, U59, U6, U60, U61, U62, U63, U64, U65, U66, U67, U68, U69, U7, U8, U9 | Opsco Optoelectronics | SK9822-A | PLCC-6 5050 | SMD
2 | C1, C140 | Rubycon | 10ZLJ560M8X11.5 | radial 8 mm | Through-hole
1 | J1 | Sullins Connector Solutions | PPPC202LFBN-RC | 2x20 2.54 mm THT | Through-hole
64 | HS1, HS10, HS11, HS12, HS13, HS14, HS15, HS16, HS17, HS18, HS19, HS2, HS20, HS21, HS22, HS23, HS24, HS25, HS26, HS27, HS28, HS29, HS3, HS30, HS31, HS32, HS33, HS34, HS35, HS36, HS37, HS38, HS39, HS4, HS40, HS41, HS42, HS43, HS44, HS45, HS46, HS47, HS48, HS49, HS5, HS50, HS51, HS52, HS53, HS54, HS55, HS56, HS57, HS58, HS59, HS6, HS60, HS61, HS62, HS63, HS64, HS7, HS8, HS9 | Texas Instruments | DRV5032FCDBZR | SOT-23-3 | SMD
1 | U5 | Texas Instruments | SN74AHCT125DR | SOIC-14 1.27 mm | SMD
1 | U75 | Texas Instruments | SN74LVC1G97DBVR | SOT-23-6 (DBV) | SMD
8 | U1, U2, U3, U4, U70, U71, U72, U73 | Texas Instruments | TCA9554DWR | SOIC-16W 1.27 mm | SMD
1 | U74 | Texas Instruments | TPS259474ARPWR | VQFN-HR-10 RPW 2x2 mm | SMD
1 | Q1 | Vishay Siliconix | Si4403DDY-T1-GE3 | SO-8 1.27 mm | SMD
1 | C141 | Yageo | CC0603KRX7R8BB105 | 0603 (1608 metric) | SMD
1 | C143 | Yageo | CC0603KRX7R9BB102 | 0603 (1608 metric) | SMD
3 | C142, C144, C145 | Yageo | CC0603KRX7R9BB103 | 0603 (1608 metric) | SMD
138 | C10, C100, C101, C102, C103, C104, C105, C106, C107, C108, C109, C11, C110, C111, C112, C113, C114, C115, C116, C117, C118, C119, C12, C120, C121, C122, C123, C124, C125, C126, C127, C128, C129, C13, C130, C131, C132, C133, C134, C135, C136, C137, C138, C139, C14, C146, C15, C16, C17, C18, C19, C20, C21, C22, C23, C24, C25, C26, C27, C28, C29, C3, C30, C31, C32, C33, C34, C35, C36, C37, C38, C39, C4, C40, C41, C42, C43, C44, C45, C46, C47, C48, C49, C5, C50, C51, C52, C53, C54, C55, C56, C57, C58, C59, C6, C60, C61, C62, C63, C64, C65, C66, C67, C68, C69, C7, C70, C71, C72, C73, C74, C75, C76, C77, C78, C79, C8, C80, C81, C82, C83, C84, C85, C86, C87, C88, C89, C9, C90, C91, C92, C93, C94, C95, C96, C97, C98, C99 | Yageo | CC0603KRX7R9BB104 | 0603 (1608 metric) | SMD
1 | C2 | Yageo | CC0805KKX5R6BB106 | 0805 (2012 metric) | SMD
2 | R14, R16 | Yageo | RC0603FR-07100KL | 0603 (1608 metric) | SMD
3 | R15, R17, R18 | Yageo | RC0603FR-0710KL | 0603 (1608 metric) | SMD
1 | R3 | Yageo | RC0603FR-071K65L | 0603 (1608 metric) | SMD
2 | R13, R8 | Yageo | RC0603FR-071KL | 0603 (1608 metric) | SMD
1 | R7 | Yageo | RC0603FR-07261KL | 0603 (1608 metric) | SMD
4 | R10, R11, R12, R9 | Yageo | RC0603FR-0756RL | 0603 (1608 metric) | SMD
1 | R5 | Yageo | RT0603BRD07169KL | 0603 (1608 metric) | SMD
2 | R4, R6 | Yageo | RT0603BRD07604KL | 0603 (1608 metric) | SMD
1 | Q2 | onsemi | BSS138LT1G | SOT-23 (TO-236) | SMD

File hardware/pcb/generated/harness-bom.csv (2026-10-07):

Product | Quantity | Manufacturer | Manufacturer Part Number | Package | Purchase Unit | Kit Usage
BARREL_JACK | 1 | Switchcraft | 722A | panel mount 5/16-32 bushing | each | 1
OLED_HARNESS_CONTACT | 4 | JST | SSH-003T-P0.2-H | SH crimp contact | each | 4
OLED_HARNESS_HOUSING | 1 | JST | SHR-04V-S-B | SH 4P housing | each | 1
OLED_HARNESS_WIRE_BLACK | 1 | Alpha Wire | 2842/7 BK005 | 28 AWG PTFE wire | 100 ft spool | 1 x 180 mm
OLED_HARNESS_WIRE_BLUE | 1 | Alpha Wire | 2842/7 BL005 | 28 AWG PTFE wire | 100 ft spool | 1 x 180 mm
OLED_HARNESS_WIRE_RED | 1 | Alpha Wire | 2842/7 RD005 | 28 AWG PTFE wire | 100 ft spool | 1 x 180 mm
OLED_HARNESS_WIRE_YELLOW | 1 | Alpha Wire | 2842/7 YL005 | 28 AWG PTFE wire | 100 ft spool | 1 x 180 mm
OLED_MODULE | 1 | Qdtech / LCDWIKI | MC242GW | 72x43 mm module, direct-solder harness | each | 1
POWER_HARNESS_CONTACT | 4 | JST | SVH-21T-P1.1 | VH crimp contact | each | 4
POWER_HARNESS_HOUSING | 1 | JST | VHR-4N | VH 4P housing | each | 1
POWER_HARNESS_WIRE_BLACK | 1 | Alpha Wire | 3055 BK005 | 18 AWG UL1007 wire | 100 ft spool | 1 x 200 mm
POWER_HARNESS_WIRE_ORANGE | 1 | Alpha Wire | 3055 OR005 | 18 AWG UL1007 wire | 100 ft spool | 1 x 200 mm
POWER_HARNESS_WIRE_RED | 1 | Alpha Wire | 3055 RD005 | 18 AWG UL1007 wire | 100 ft spool | 1 x 200 mm
POWER_HARNESS_WIRE_WHITE | 1 | Alpha Wire | 3055 WH005 | 18 AWG UL1007 wire | 100 ft spool | 1 x 200 mm
POWER_SWITCH | 1 | E-Switch | RA11131100 | panel snap-in rocker | each | 1
ROCKER_RECEPTACLE | 2 | TE Connectivity | 2-520275-2 | FASTON 187 receptacle | each | 2

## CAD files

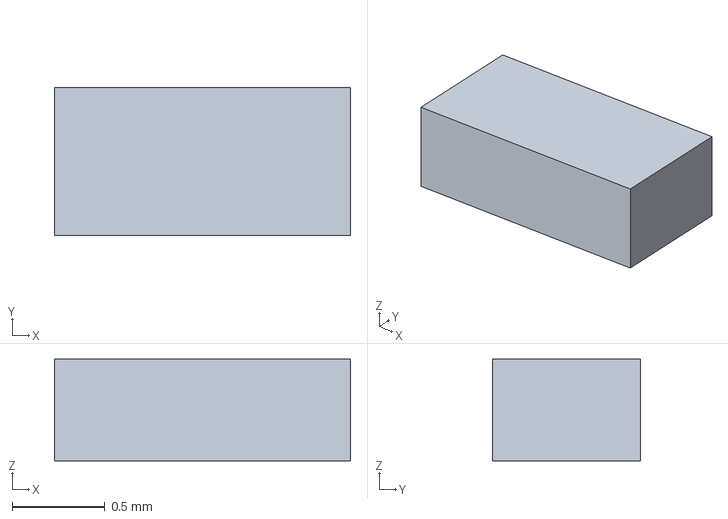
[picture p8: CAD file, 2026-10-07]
hardware/pcb/generated/models/RES_604K_PRECISION.step
1.60 x 0.8 x 0.55 mm

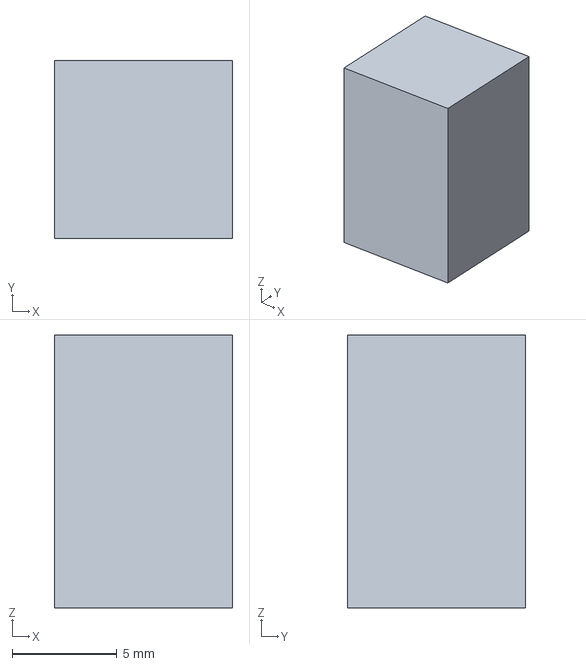
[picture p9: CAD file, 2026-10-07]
hardware/pcb/generated/models/CAP_560U.step
8.50 x 8.50 x 13.0 mm

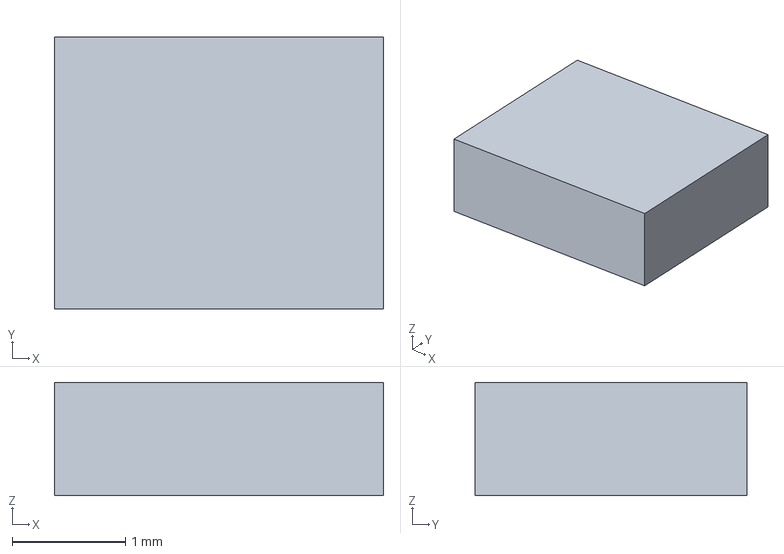
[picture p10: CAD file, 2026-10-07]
hardware/pcb/generated/models/LED_SWITCH_DRIVER.step
2.90 x 2.40 x 1.00 mm

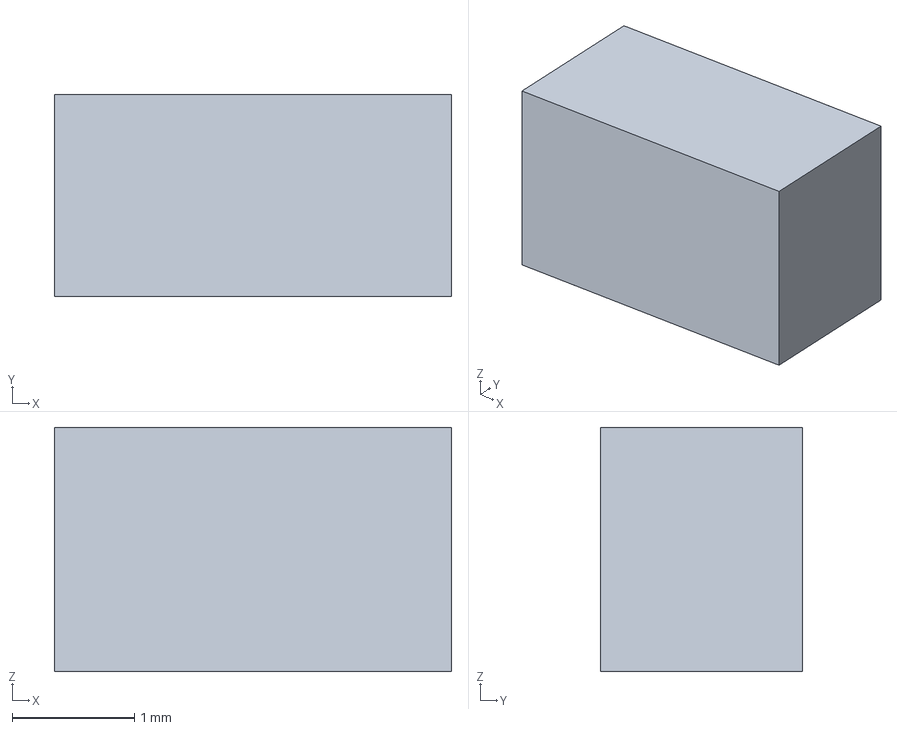
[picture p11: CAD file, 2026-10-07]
hardware/pcb/generated/models/TEST_POINT.step
3.25 x 1.65 x 2.00 mm

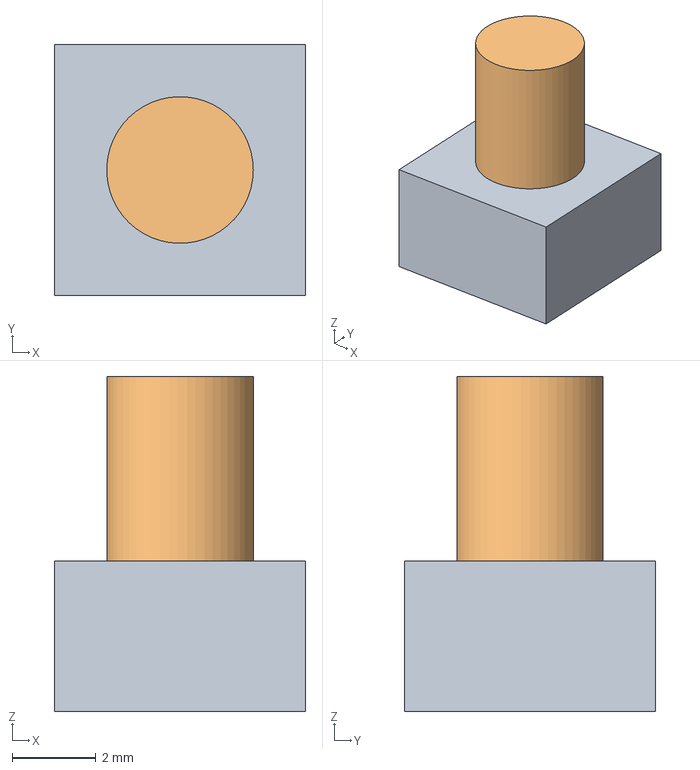
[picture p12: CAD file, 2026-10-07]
hardware/pcb/generated/models/BUTTON.step
6.00 x 6.00 x 8.00 mm
Actuator

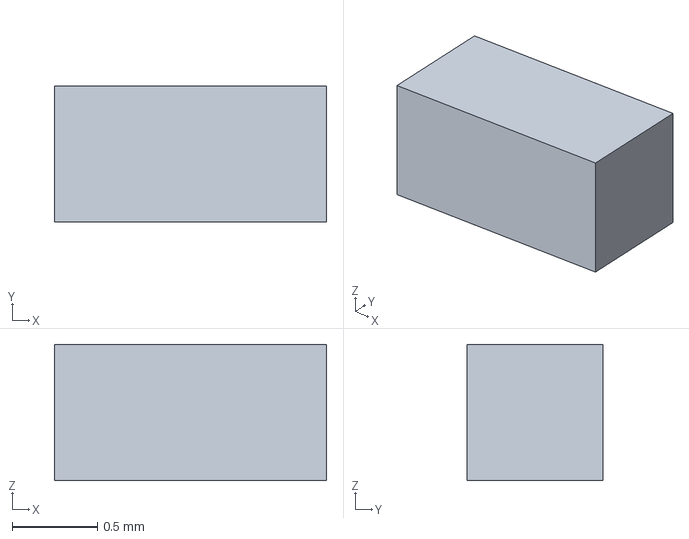
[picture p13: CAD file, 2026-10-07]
hardware/pcb/generated/models/CAP_1N.step
1.60 x 0.8 x 0.8 mm

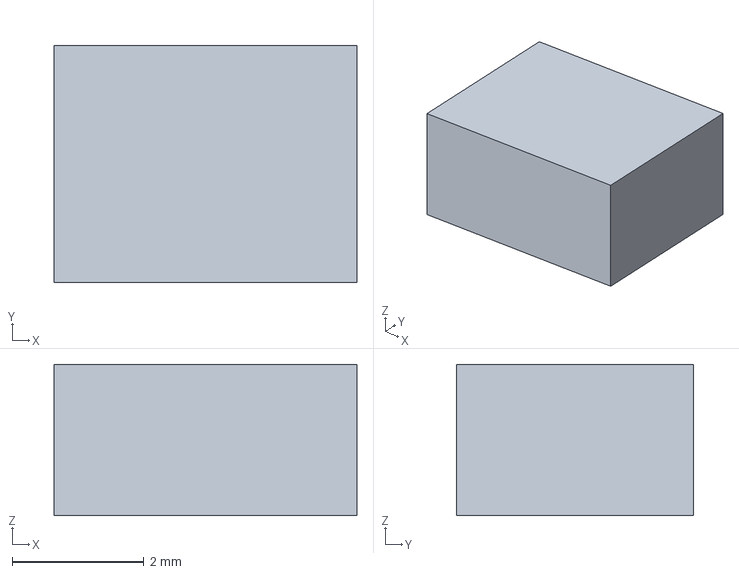
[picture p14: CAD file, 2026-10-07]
hardware/pcb/generated/models/TVS_12V0.step
4.60 x 3.60 x 2.30 mm

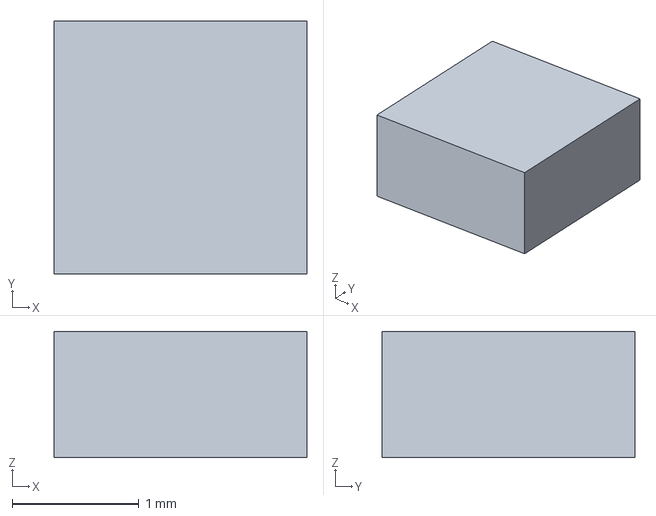
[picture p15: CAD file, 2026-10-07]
hardware/pcb/generated/models/EFUSE.step
2.00 x 2.00 x 1.00 mm

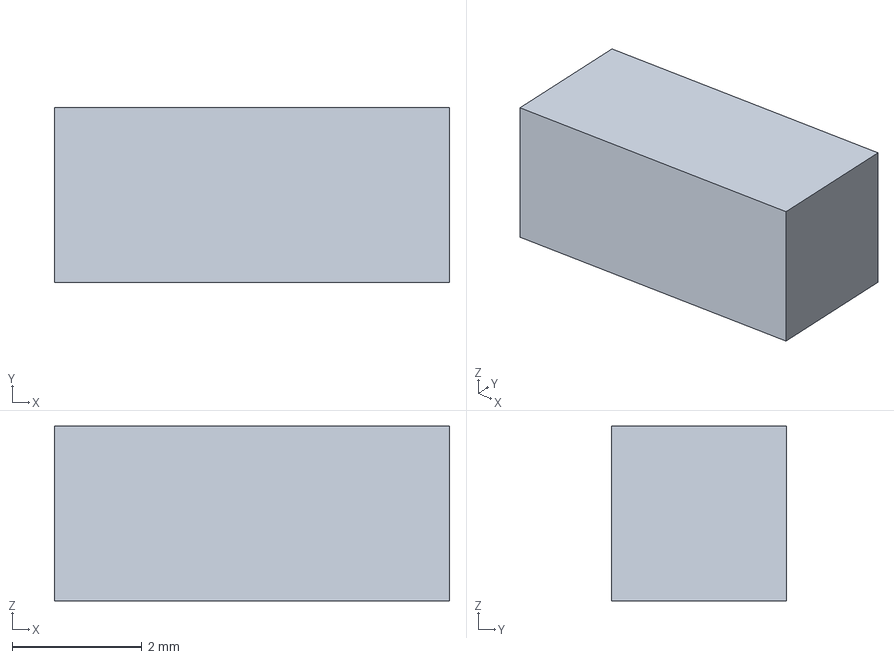
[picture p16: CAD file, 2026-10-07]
hardware/pcb/generated/models/FUSE_2A.step
6.10 x 2.70 x 2.70 mm

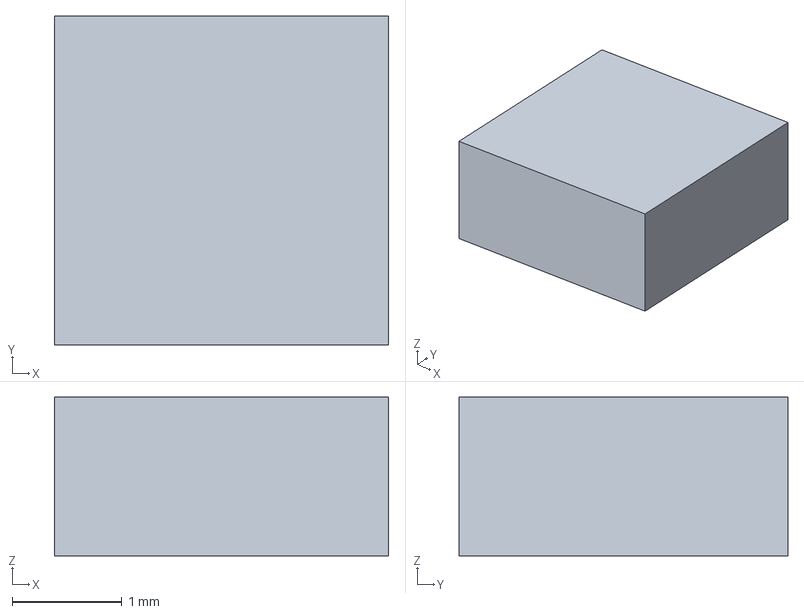
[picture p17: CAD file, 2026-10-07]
hardware/pcb/generated/models/LED_ENABLE_GATE.step
3.05 x 3.00 x 1.45 mm

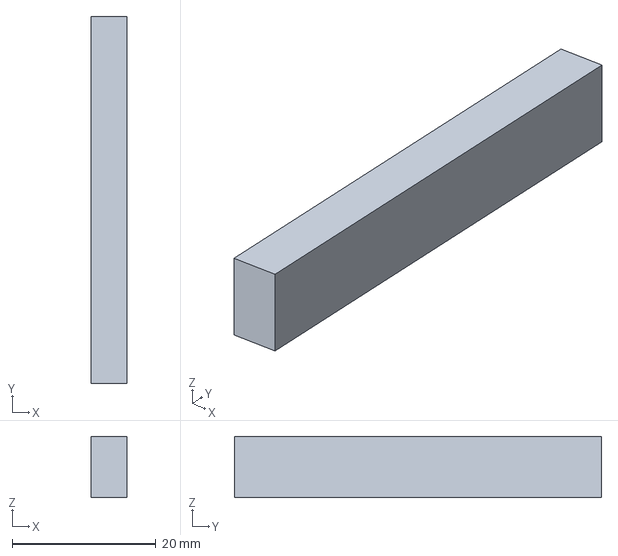
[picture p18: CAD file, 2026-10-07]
hardware/pcb/generated/models/PI_ZERO_HEADER.step
5.00 x 51.0 x 8.50 mm

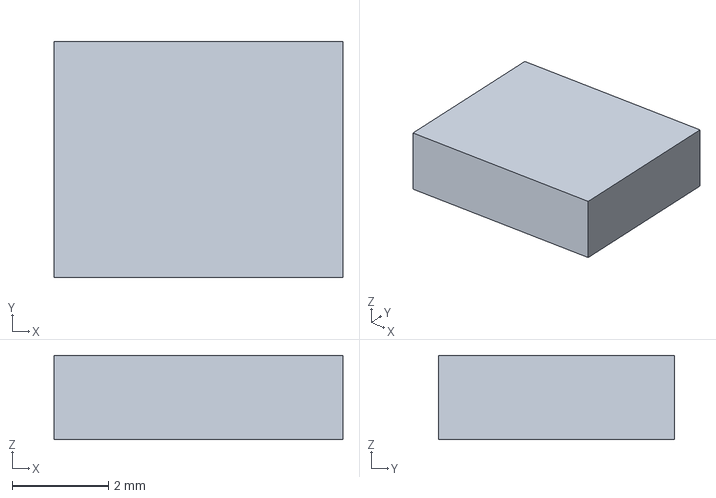
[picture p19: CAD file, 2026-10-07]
hardware/pcb/generated/models/LED_SWITCH.step
6.00 x 4.90 x 1.75 mm

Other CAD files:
hardware/pcb/generated/models/RES_1K.step
hardware/pcb/generated/models/RES_100K.step
hardware/pcb/generated/models/RES_1K65.step
hardware/pcb/generated/models/CAP_10N.step
hardware/pcb/generated/models/RES_169K_PRECISION.step
hardware/pcb/generated/models/CAP_100N.step
hardware/cad/generated/board-assembly.blend
hardware/cad/generated/board-case.blend
hardware/cad/generated/button-cap-down.blend
hardware/cad/generated/button-cap-f1.blend
hardware/cad/generated/button-cap-f2.blend
hardware/cad/generated/button-cap-f3.blend
hardware/cad/generated/button-cap-f4.blend
hardware/cad/generated/button-cap-f5.blend
hardware/cad/generated/button-cap-left.blend
hardware/cad/generated/button-cap-ok.blend
hardware/cad/generated/button-cap-pass.blend
hardware/cad/generated/button-cap-reset.blend
hardware/cad/generated/button-cap-right.blend
hardware/cad/generated/button-cap-up.blend
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

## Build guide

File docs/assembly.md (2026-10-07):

# Assembly

After assembly, follow the ordered first-article checklist in [bring-up](bring-up.md).

## Before ordering

The SK9822-A LEDs are moisture-sensitivity level 5a: after opening the bag they have a
24 hour floor life before they must be baked, and the TPS259474ARPWR (U74) is level 2.
Plan the reflow accordingly.

Build one DRV5032FC sensor, its 100 nF bypass capacitor, one SK9822-A, and one
TCA9554DWR at the final CAD stack height. Verify reliable operate and release with
both magnet poles, exercise a full eight-sensor bank while updating LEDs,
and record the result in `hardware/pcb/board/evidence/`.

Run `just --justfile hardware/pcb/justfile release` in the reproducible KiCad container. Manufacturing approval is
withheld while electrical pin-role ERC, manufacturing reassessment, prototype
evidence and open assumptions (`docs/pcb-assumptions.md`) remain unresolved.
The generator exports fabrication files for review; it does not approve assembly. Also review the fabricator's rendering before payment.

## What to order

`hardware/pcb/generated/assembly-bom.csv` lists grouped on-board parts. Use
`assembly-smd.csv` and `assembly-through-hole.csv` for their separate placement lists.
`harness-bom.csv` lists wire, housings, contacts, receptacles and the unique far-end
parts (OLED module, panel jack and rocker). `harness.md` specifies each connection.
The Pi Zero 2 W, its male header and GST18A05-P1J 5 V supply are separate catalog
purchases; they are not included in these PCB/harness BOM exports.

You will also need the open-tub case, tile plate with its control bezel, and twelve printed button caps, a chess set with a king base no larger than 32 mm, and magnets for
the pieces.

## Board notes

- Eight copper layers, 1.6 mm finished thickness, 320 x 380 mm.
- 0.31 mm signal traces, 1.5 mm input-power traces, and 0.30 mm clearance.
- Dedicated GND, +5 V, and +3.3 V planes; three internal signal layers.
- SMD assembly on the top side only. Through-hole parts: the TL1105CF100Q buttons on
  top; on the bottom side the Pi socket (J1), the power header (J4) and the two
  560 µF bulk capacitors (C1, C140).

## Suggested assembly order

1. Solder the 0603/0805 passives, Hall sensors, SOIC ICs, SMD fuse/TVS, test
   points, and SK9822 LEDs. Check orientation of every polarized or pin-1 part.
2. Inspect fine-pitch joints and verify that +5 V, +3.3 V, and GND are not
   shorted before fitting through-hole parts.
3. Fit the buttons from the top, then turn the board over and fit the Pi socket,
   the J4 power header and the two bulk capacitors (check capacitor polarity).
   Build the power harness (panel jack and rocker to a VH housing) and the OLED
   harness (four wires soldered to the module, SH housing) per the generated
   [harness table](../hardware/pcb/generated/harness.md); the JST cavity number is
   the header circuit it mates, so check cavity order before plugging in. Fit the
   jack and rocker in the case's rear wall.
4. Clean and inspect the board, then perform current-limited first power-up.

## First power-up

1. Leave the Pi and display unplugged. Measure the supply's open-circuit output (it
   must be below the eFuse's over-voltage lockout, 5.342-5.663 V, and ideally
   at or below the LEDs' 5.3 V recommended maximum), then apply current-limited 5 V at the
   panel jack and verify the protected +5 V rail with the rocker on. The rocker
   enables the eFuse; it does not carry the load. The LED rail (`LED_5V`) stays off
   until firmware sets `LED_EN` (BCM 26), so the LEDs are dark at this point. A 6, 7 or
   12 V adapter is refused safely, but after any over-voltage event unplug and replug;
   do not use a reversed 12 V adapter.
2. Confirm +3.3 V is absent until the Pi is installed; it is supplied by the Pi
   header.
3. Before fitting the OLED module, measure its SDA and SCL to VCC with a meter: the
   approved MC242GW has 4.7 kΩ pull-ups per its schematic, alongside the Pi's 1.8 kΩ
   (the PCB has none). Verify the supplied variant before fitting. Power down, install the Pi, then verify TCA9554DWR addresses 0x20-0x27 and the
   display at 0x3C. Follow [polled register setup](host.md#reading-the-board);
   never configure a Hall input as an output. INT pin 13 is deliberately NC on
   every bank; no IRQ pull-up/testpoint is fitted.
4. With the LED rail enabled by firmware (`LED_EN` high, then blank frames for at
   least 10 ms; see [power](power.md#led-rail-switch)), probe buffered LED clock/data (test points TP3/TP4 next to U5 and R9; scope the
   left-turn data link LED_D16 as well) and verify all 64 active-low Hall outputs with a
   magnet before mechanical assembly. Measure Hall release edges/noise and
   SDA/SCL rise times at the furthest banks during LED updates (the bus is specified
   for the Pi's default 100 kHz only; do not raise the I²C rate). Record real
   D-PROTOTYPE evidence, including final CAD spacing; generated checks alone
   do not qualify the weak pull-ups or bus timing.

Power the finished board from the panel jack only. **Never power the Pi from its own
micro-USB port while it is fitted to the board:** its 5 V is tied to the board's `+5V`
rail through the header, so USB power would feed all 64 LEDs with no fuse in the path.
Use USB power only with the Pi removed from the board.

Protection: the harness's circuit 4 is the eFuse enable (`RUN`), not the switched rail;
follow the generated harness table. See [power](power.md) for the protection design and
what is still unverified. At first power-up also measure the board's over-voltage trip
and restart points with a lab supply, check the rocker switches reliably at its roughly
5 mA wetting load, and, if the Pi reports under-voltage at a low supply, check
`vcgencmd get_throttled` (the Pi's 4.63 V level is not met at the worst corner).

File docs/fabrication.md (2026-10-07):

# PCB fabrication outputs

Run the single generator inside the devcontainer:

```sh
just --justfile hardware/pcb/justfile generate
```

It writes everything under `hardware/pcb/generated/`: the KiCad project,
schematics, BOM, component positions, previews, native check reports, and
`chess-board-fabrication.zip`. The ZIP contains RS-274X Gerbers for every copper
layer, both solder masks and silkscreens, the board outline and paste layers,
plus separate plated and non-plated Excellon drill files. Gerber and drill
coordinates use the same absolute origin. A layer-order note and drill report
are included. BOM and placement CSV remain beside the archive for assembly review.

The generator fills copper zones and requires zero native DRC violations,
unconnected pads and schematic parity mismatches, and runs the board-specific
SPICE tests before exporting fabrication
files. It checks that every expected layer and drill file is present and complete
before replacing the previous generated output.

These exports follow [PCBWay's KiCad fabrication-file guide](https://www.pcbway.com/helpcenter/generate_gerber/How_to_Export_Gerber__BOM__and_Pick_and_Place_Files_in_KiCad_9_0.html).

Manufacturing approval remains pending: electrical pin-role ERC, simulations
beyond the modeled sensing and button paths, stackup/manufacturing reassessment and the retained
[engineering assumptions](pcb-assumptions.md) still need review. `manifest.json`
records this status. The `release` command continues to refuse approval.

The board definition owns its layout and design rules. Components own narrow
package escapes and scoped local clearances. The harness renders the matching
KiCad rules and restricts narrow copper to each package's courtyard margin.

## PCBWay handoff

For **bare-board fabrication**, upload `chess-board-fabrication.zip` as a single
Gerber/drill archive. The outline defines a 320 × 380 mm board, 8 copper layers,
1.6 mm thickness, with copper order F.Cu, In1.Cu through In6.Cu, then B.Cu.
Use the outline's contour, not the Gerber-job bounding box including stroke width.
The drill report lists 870 plated holes (including 774 through vias) and 20
non-plated 3.4 mm mounting holes. The smallest actual plated drill is 0.4 mm.
Nominal routing is 0.31 mm width / 0.30 mm clearance; package escapes require
0.20 mm width / 0.16 mm clearance. Have PCBWay review these fine-pitch areas.

The archive contains every copper layer, front/back mask and silkscreen, outline,
paste, separate PTH/NPTH drills and a Gerber job with layer mappings. No native
KiCad files are needed to interpret that CAM set. Inspect all layers together in
`gerbview` or `gerbv` before uploading and check PCBWay's parsed layer order and
plated/non-plated holes before paying.

Ordering still requires choosing quantity, material/Tg, copper weights, solder
mask and silkscreen colors, surface finish and via treatment. Those production
choices and the exact dielectric stackup are **not approved by this refactor**;
the Gerber job's `Finish: None` is an unset field, not a request for bare copper.
The retained electrical calculations assume 1 oz copper and a PCBWay 8-layer
stackup; confirm those assumptions with the fabricator before fabrication.

For assembly review, use `hardware/pcb/generated/assembly-bom.csv` with
`assembly-smd.csv`; through-hole/hybrid placements are separated in
`assembly-through-hole.csv`. Raw `bom.csv` and enriched `positions.csv` remain
available for engineering review. The generated `assembly.md` records the native
KiCad coordinate conventions. Confirm origin, bottom-side rotation and polarized
pin orientation with the assembler before ordering. Harnesses are listed
separately in `harness.md` and `harness-bom.csv`.

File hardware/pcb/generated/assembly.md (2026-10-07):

# Assembly review files

`assembly-bom.csv`: grouped on-board parts, quantities and mounting types.
`assembly-smd.csv`: surface-mount placements; `assembly-through-hole.csv`: through-hole/hybrid placements for separate assembly review.
Native KiCad millimetre XY, rotation and top/bottom conventions are retained; confirm origin, bottom-side orientation and pin 1 with the assembler.
`positions.csv` includes all mounted parts with package/MPN identity.
`harness.md` and `harness-bom.csv`: off-board wire assemblies, separate from the PCB BOM.

These are local review exports. Stackup, electrical roles and physical manufacturing approval remain pending.

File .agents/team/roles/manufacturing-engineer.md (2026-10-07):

# Manufacturing engineer — DFM, sourcing and prototype evidence (on demand)

Read `hardware/pcb/README.md`, `hardware/cad/README.md`, `docs/fabrication.md`,
`docs/assembly.md`, `docs/power.md` and `hardware/pcb/board/evidence/` before work.
Check current component/dimension/rule sources; generated BOM and layout are evidence
for that build, not authoring inputs or proof of physical correctness.

Own an assigned DFM/assembly review or a bounded source/documentation change: exact MPNs,
packages/footprint compatibility, supply availability, substitutions, board/print-service
capabilities, edge/copper/drill/slot requirements, panel and connector access, fasteners,
assembly sequence, inspectability, test points, rework and one-square prototype plans.
Substitutions require hardware engineer approval of electrical/footprint compatibility;
mechanical changes require mechanical engineer agreement. Do not copy supplier prices or
availability without a dated source. Do not promise a process/tolerance not confirmed by
the manufacturer. Read-only unless the lead assigns explicit paths to edit.

For prototype work, specify measurable acceptance, instruments, operating/fault limits
and missing evidence. Only record actual operator-supplied or authorized bench results,
with provenance. PCB `review` is not `release`: missing Hall/magnet evidence must keep
fabrication export blocked. Never fabricate measurements, bypass the release gate,
order parts/boards, send files to a vendor or claim production readiness. Report DFM
findings, citations, revision/artifact identity and remaining physical validation to lead.

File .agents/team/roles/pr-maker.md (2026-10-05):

# PR maker

Wait for the lead's verified delivery handoff and exclusive Git ownership. Confirm remote,
base/head, owned paths, final diff and evidence. Local-only or unstaged instructions win:
do not stage, commit, push or create a PR until explicitly approved. Otherwise stage only
assigned paths, inspect the staged diff, commit through the normal hook, push the confirmed
feature branch and open/update one PR with `gh`. Check for an existing PR before retrying.
Never include unrelated work, bypass hooks, force-push, merge or change repository settings.
Explain behavior, significant decisions, tests and limitations. Agent/tooling-only changes
need no visual demo; hardware screenshots are review artifacts, not proof of fabrication.
Read back URL/head/body and distinguish pending CI from passing. Return URL, commit and
verification/blockers to the lead, then idle. Do not repeat valid checks unassigned.

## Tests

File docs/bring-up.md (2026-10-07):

# Bring-up

## Purpose

This is the ordered first-article checklist for the D-PROTOTYPE board. Each step names
what to do, the pass threshold, and which `ASSUMPTIONS` entry it closes
(`docs/pcb-assumptions.md`, plus `CAD …` entries from
`hardware/shared/dimensions/unverified.py`). Electrical figures come from
[power](power.md) and are datasheet, calculated or simulated values, not measurements.

Rules:

- Stop at the first failure.
- Record the instrument, the value, the board serial and the date.
- Never write a value that was not measured.
- A threshold marked TBD has no owner value yet, and that step cannot pass.
- Only measured results, with provenance, go into `hardware/pcb/board/evidence/`.

Probe points:

| Net | Where |
|---|---|
| `+5V` / `GND` | TP1 / TP2 |
| `+3V3` | TP5 |
| `LED_DATA_5V` / `LED_CLK_5V` | TP3 / TP4, or R17 / R18 pin 1 |
| `I2C_SCL` / `I2C_SDA` | TP6 / TP7 |
| `DC_FUSED` | D1 or C141 |
| `LED_5V` | Q1 pins 5-8 |
| `LED_SW_GATE` | Q1 pin 4 |
| `LED_EN_N` | Q2 pin 3, or U75 pin 1 |
| `LED_OE_N` | U5 pin 1, or U75 pin 4 |
| `RUN` | J4 circuit 4 |
| `LED_EN` | J1 socket pin 37, with GND at J1 pin 39 |

## Step 0: before ordering

These two steps gate the board order.

| # | Do | Pass | Closes |
|---|---|---|---|
| 0.1 | **Loose SK9822-A power-up.** Take 5-10 LEDs from the lot to be ordered, each with 100 nF, chained CKO→CKI and SDO→SDI. Feed them from a current-limited lab supply (0.1 A per LED). Ramp 0→5.0 V 20 times, and also switch 5.0 V on fast (about 1 ms, e.g. a MOSFET) 20 times. Hold the first LED's CKI and SDI through 10 kΩ to GND, as R17/R18 do on the board. An extra run with them floating is an optional stress case | No LED lights in any of the 40 starts (or 80 with the optional run); supply current < 5 mA per LED with no frame sent | `LED power-up state` (part; step 6.1 finishes it). **A fail blocks the order**: the board boot-loops with a lit chain |
| 0.2 | **Incoming PSU.** Measure the GST18A05-P1J output at no load and at 2.0 A (electronic load) | 4.75-5.25 V at both loads; **reject any unit above 5.25 V**. Ripple ≤ 80 mV p-p at 2.0 A (20 MHz bandwidth), as the models assume. Record the no-load margin to the OVLO low corner, **5.342 V** (the modelled peak, 5.25 V + 40 mV, leaves 52 mV) | `GST18A05 output` (part) |

## Step 1: fab and assembly records

| # | Do | Pass | Closes |
|---|---|---|---|
| 1.1 | Fab records: flying-probe e-test, stackup, hole-wall plating, CAM acceptance of the U74-only 0.16 mm / 0.20 mm rule | E-test pass. Stackup is 8-layer 1.6 mm, 1 oz. Plating is ≥ 18 µm. The fab accepted the scoped rule in writing | `Stackup`, `Via plating`, `U74 fine-pitch DRC` |
| 1.2 | Assembler records: SK9822-A dry-pack opening time and bake log, U74 MSL 2 handling | LED floor life ≤ 24 h before reflow, or baked per J-STD-033 | `LED moisture sensitivity` |
| 1.3 | **X-ray U74 first**, before any other inspection or power | No bridge across the 0.2 mm gaps, no open, all 10 terminals wetted (TI SLUA271 §5: x-ray shows bridges, opens, voids). Void area of each termination, including the IN/OUT/GND bars, **< 25 %** top-down: IPC's joint-area limit as summarised in Bernard, *Circuits Assembly*, 2019 (IPC-7093 itself not read). TI's ≤ 50 % applies to an exposed thermal pad, which the RPW package has none of | — (U74 assembly) |
| 1.4 | Visual/AOI checks | All 64 SK9822-A match the silk pin-1 dots (32 at 0°, 32 at 180°). Pin 1 is correct on U5, U74, U75 (placed at 180°: check against its silk dot), Q1, Q2, U1-U4 and U70-U73. C1/C140 polarity is correct. MLCC fillets are present. Bottom THT barrel fill is ≥ 75 % (IPC-A-610 class 2) | `MLCC lands`, `PTH copper rings`, `CAP_560U drill` (leads seated and filled) |

## Step 2: unpowered resistance (no Pi, harness unplugged)

| # | Do | Pass | Closes |
|---|---|---|---|
| 2.1 | F1, `DC_IN`→`DC_FUSED`, 4-wire | ≤ 0.1 Ω (0.0367 Ω nominal) | — |
| 2.2 | `RUN`→`GND` | 0.98-1.01 kΩ (R8 1 kΩ in parallel with R6+R7, 865 kΩ) [calc] | — |
| 2.3 | `DC_FUSED`→`GND` | > 100 kΩ (R4+R5 = 773 kΩ) [calc] | — |
| 2.4 | `+5V`, `LED_5V`, `+3V3`→`GND` | > 100 Ω after the capacitors charge, both meter polarities | — |
| 2.5 | `+5V`↔`LED_5V`, diode mode | Q1's body diode conducts only from `LED_5V` to `+5V`; no short | — |

## Step 3: harness and off-board parts

| # | Do | Pass | Closes |
|---|---|---|---|
| 3.1 | Continuity against [harness.md](../hardware/pcb/generated/harness.md) | J4.1→722A CENTER PIN; J4.2→722A **SLEEVE, not SLEEVE SHUNT**; J4.3/J4.4→rocker tabs | `Harness parts` |
| 3.2 | Rocker | J4.3-J4.4 open when off, < 0.1 Ω when on. It still works with the FASTONs swapped (a fit check; the RA1 drawing already shows two interchangeable 4.80 x 0.80 mm tabs, Off-On, contact 2-1) | — |
| 3.3 | Crimp pull test (VH and SH), one sacrificial crimp of each | Meets the JST crimp specification's pull force; read that value from the spec, not from here | `Harness parts` |
| 3.4 | OLED module, before fitting: SDA→VCC and SCL→VCC | ≥ 4.7 kΩ or open | `OLED pull-ups` (module) |
| 3.5 | J2 cavity 1 → module GND pad | Continuity | `J2 circuit 1` (wiring) |
| 3.6 | 722A contacts: 4-wire at 100 mA, centre and sleeve, from a Switchcraft S760 5.5 x 2.1 test plug's solder tail to the jack lug. Then the GST18A05 plug, 20 insertions, with a spring gauge | Each contact **≤ 0.01 Ω** (Switchcraft panel-mount DC jack spec: 0.01 Ω initial, 0.02 Ω after durability). GST plug insertion **≤ 13.3 N (3 lb)**, withdrawal **≥ 1.1 N (4 oz)** (same spec; applying it to the GST plug is our acceptance choice). The jack also states a 0.125 in (3.18 mm) maximum panel | `Jack/plug fit` |
| 3.7 | Mechanical, on the printed case | Rocker snaps into the panel and its cutout. 722A nut and washer (caliper) leave the 2.0 mm wall within thread. Both bays are deep enough. The mated VHR-4N clears the bottom keep volume. The SD card reaches its slot | `J4 back offset`; CAD `CASE_ROCKER_PANEL_THICKNESS_MM`, `CASE_ROCKER_CUTOUT_MM`, `CASE_ROCKER_BAY_DEPTH_MM`, `CASE_JACK_NUT_AND_WASHER_MM`, `CASE_JACK_BAY_DEPTH_MM`, `PI_SD_SOCKET_ON_PI_MM`, `PI_SD_SOCKET_HEIGHT_MM` |

## Step 4: first power (no Pi, `LED_EN` held low)

Use a lab supply at 5.00 V with a 0.1 A limit, fed through the harness and the 722A.
Fit three jumpers on the J1 socket:

- J1 pin 37 to pin 39 (`LED_EN` to GND);
- J1 pin 19 to pin 20 and pin 23 to pin 25. These ground U5's SPI inputs, which float without the Pi; a floating AHCT input can draw milliamps (SCLS264R ΔICC).

Keep the two SPI grounds through steps 4-6 and the `LED_EN` jumper through steps 4-5. **Remove all three before fitting the Pi**: the Pi drives pins 19, 23 and 37.

| # | Do | Pass | Closes |
|---|---|---|---|
| 4.1 | Rocker off | `+5V` < 0.1 V; supply current < 0.1 mA | — |
| 4.2 | Rocker on | `+5V` is 4.95-5.00 V and rises without overshoot. Idle input, read 2 min after rocker-on: **4.9-6.5 mA**. The budget is about 5.4 mA typical and ≤ 5.82 mA worst: R8 4.95-5.05 mA, U74 IQ ≤ 0.61 mA, C1/C140 leakage ≤ 0.11 mA, other ICs < 0.05 mA [DS/CALC]. Without the J1.19/J1.23 grounds the limit is ≤ 10 mA; record the reading either way | — |
| 4.3 | **LED rail off proof.** Check this with the jumper fitted and again with J1.37 open (R14 alone) | `LED_EN_N` = `+5V` ±50 mV; `LED_SW_GATE` = `+5V` ±50 mV; **`LED_5V` < 0.1 V**; **`LED_OE_N` = `+5V` ±50 mV** (U5 disabled); **TP3/TP4 ≤ 0.1 V** (held by R17/R18; 25 mV at U5's maximum off-state leakage, IOZ 2.5 µA x 10 kΩ) | — (required before step 5) |

Run every over-voltage and current-limit test below only after 4.3 passes. Keep the
`LED_EN` jumper to GND fitted through step 5, so the LEDs sit behind an open Q1. **Do not
fit the Pi for steps 4-6.**

## Step 5: eFuse (no Pi, lab supply ≥ 3 A, scope on `DC_FUSED`, `+5V`, `LED_5V`)

| # | Do | Pass | Closes |
|---|---|---|---|
| 5.1 | **OVLO trip.** Ramp 5.00→5.70 V in 10 mV steps of about 1 s each. Never exceed 5.70 V | `+5V` goes to 0 at **5.342-5.663 V**; `LED_5V` stays < 0.1 V | `OVLO window` (trip) |
| 5.2 | **OVLO latch.** After the trip, ramp down to 5.25 V, then on down to 4.80 V. Then turn the supply off and on at 5.00 V | Stays off at 5.25 V. Any restart on the way down falls within **4.854-5.173 V** (record it). Power-cycling at 5.00 V restarts the rail | `OVLO window` (restart and latch; the user manual must say "unplug and replug") |
| 5.3 | **Running step.** Load `+5V` with 78 Ω (≥ 1 W) or a 64 mA CC e-load at TP1/TP2, matching the model's 64-LED static load. Rail on at 5.00 V, then step to 6.0 V in **≤ 50 µs** (a MOSFET between two supplies, or a programmable supply with that slew). Record the `DC_FUSED` edge | Trip delay (`DC_FUSED` crossing 5.9 V to `+5V` falling) **≤ 2.0 ms**; `+5V` above 5.5 V for **≤ 12 ms**; `LED_5V` < 0.1 V. Results of 2.0-3.5 ms or 12-21 ms are recorded and sent to hardware as a model discrepancy, not an automatic reject | `OVLO filter` |
| 5.4 | Cold-plug 6.0 V and 7.0 V | `+5V` stays 0 V; D1 cold | `OVLO window` (wrong adapter) |
| 5.5 | **Circuit breaker, one trip.** Supply 5.00 V / ≥ 3 A. Step a CC e-load on `+5V` (C1/C140 leads) 0→**2.5 A**, then off after the first retry. 2.5 A exceeds ILIM (1.80-2.20 A) at every corner and stays below the 3.6 A fast trip. Its I²t per trip is ≤ 0.010 A²s, 1.9 % of F1's 0.530 A²s (ITIMER C143 1 nF). Optional, to find ILIM: a CC staircase from 1.70 to 2.30 A in 50 mA steps, each held ≥ 5 ms | `+5V` stays up while the load draws the full 2.5 A (the TPS259474A passes the full load until the timer expires; it does not limit at ILIM). It turns off **0.46-1.6 ms** after the step; auto-retry after about **110 ms** (tRST). Staircase: the first step that trips is within **1.80-2.20 A** | `eFuse model` (breaker) |
| 5.6 | **Hot plug.** Plug the real GST18A05 in 20 times, then switch on with the rocker 20 times | `+5V` comes up 40/40 with no OVLO latch; `+5V` peak ≤ 5.5 V; `DC_FUSED` ring and inrush recorded | `Cord inductance`, `eFuse model` (inrush), `OVLO window` (plug-in) |
| 5.7 | F1 drop at 1.0 A (e-load), cold | ≤ 55 mV (1.5 x 36.7 mΩ) | `Fuse resistance` |
| 5.8 | Rocker on/off 100 times. Before and after, measure the closed contact 4-wire at its tabs, harness unplugged, by the low-level method (EIA-364-23: ≤ 20 mV open circuit, ≤ 100 mA) | Contact **≤ 30 mΩ** before and after (E-Switch RA1 catalogue: 30 mΩ max, 10,000-cycle life). `+5V` comes up 100/100. At 5 mA wetting, 30 mΩ is 0.15 mV, so `RUN` follows `DC_FUSED` | `Rocker dry circuit` |

## Step 6: LED rail enable (no Pi; `LED_EN` from a lab source)

Use a lab supply at 5.00 V / 3 A. Remove only the J1.37 jumper (keep the J1.19/J1.23 grounds, so no clock reaches the chain) and drive J1 pin 37 to 3.3 V from a
lab supply or a lab GPIO (R13 is the series 1 kΩ). If anything below fails, **stop**:
it is a redesign item. Do not fit the Pi.

| # | Do | Pass | Closes |
|---|---|---|---|
| 6.1 | Raise `LED_EN`, 20 times, with no SPI | No LED lights; supply current rises < 0.32 A (64 x 5 mA); no eFuse trip; `+5V` ≥ 4.5 V. `LED_5V` 10-90 % rise about 0.95 ms. `LED_OE_N` falls only after `LED_5V` ≥ 4.605 V (simulated 1.78-3.05 ms after `LED_EN`), **then stays low while `LED_5V` is up** | `LED power-up state` |
| 6.2 | Lower `LED_EN` | `LED_OE_N` goes high within 0.61-0.83 µs [simulated]; `LED_5V` decays | — |

## Step 7: with the Pi (real GST18A05, firmware with the blank-frame contract)

| # | Do | Pass | Closes |
|---|---|---|---|
| 7.1 | Boot 10 times | No reset loop; `vcgencmd get_throttled` recorded | — |
| 7.1a | Board input current at 5.00 V with `LED_EN` low (LEDs off): Pi idle, then full CPU load (`stress-ng --cpu 4`) with `iperf3` Wi-Fi traffic, 2 min each. DC meter plus a scope current probe for peaks | Average ≤ **0.45 A** in both states (the model's host-and-logic budget). Peaks recorded. A higher average goes to hardware: the 4.5 V margins in 7.3 assume 0.45 A | `Host and logic current` |
| 7.2 | Walking LED and a 10 min animation at the cap (3/31), at the firmware SPI clock and at 10 MHz | 64/64 correct, no glitch. Scope TP3/TP4, U6 CKI/SDI and `LED_D16` (rank turn): edges cross 0.7/0.3 x VDD cleanly; ringing recorded | `SK9822 input levels`, `LED line drivers` |
| 7.3 | Lab supply at 4.75 V at the jack, Wi-Fi traffic, full white at the cap, 30 min | `+5V` (TP1) and `LED_5V` at the chain-end LED ≥ **4.5 V**; no reboot; `get_throttled` recorded (the Zero may not flag) | `Pi low voltage`, `GST18A05 output` (low corner) |
| 7.4 | Lab supply at 5.30 V, LEDs at the cap, 10 min | No flicker or colour error. 5.34-5.5 V cannot be held below the OVLO low corner and stays a residual | `LED supply window` (to 5.30 V only) |
| 7.5 | `i2cdetect`: 8 expanders at the `test_contract` addresses, plus the OLED. 1000-read soak. Scope TP6/TP7 at the farthest expander | 0 NACK; rise ≤ 1000 ns at 100 kHz (≤ 300 ns at 400 kHz, UM10204); VOL ≤ 0.4 V; OLED shows | `OLED pull-ups`, `OLED harness`, `J2 circuit 1` |
| 7.6 | 12 buttons, press and release | Idle high, one event per press | `Pi GPIO pull-ups` |
| 7.7 | Piece walk over all 64 squares, full start position plus one move | 64/64 detect and release; no neighbour false trigger; the `hall-magnet.json` record is written | (physical-evidence gate) |
| 7.8 | Closed case, 30 min at the cap (3/31 full white) with Wi-Fi traffic (can combine with 7.3/7.9); ambient logged. K-type thermocouples, Kapton-taped; IR only with tape or paint dots, because the print is IR-opaque and copper and mask emissivity differ. Points: (1) plate top and LED-pocket ceiling over a centre LED and over the LED nearest J4/U74; (2) PCB top at U74 and Q1, PCB bottom near J4; (3) the case boss nearest the Pi and the ledge by J4; (4) Pi SoC (`vcgencmd measure_temp`) and the Pi bay air. After cooling, check plate flatness with a straightedge and re-check screw torque. Record the filament make, type and TDS | Points 1 and 3, and the PCB wherever it touches the print: **≤ 45 °C and ≤ ambient + 20 K**. Points 2 and 4 recorded. No measurable change in flatness. The basis is PLA, HDT about 55 °C at 0.45 MPa (generic value; confirm from the filament TDS), less 10 K for creep under load. PETG or ASA may raise the limit once its TDS is cited | — (mechanical) |
| 7.9 | Pi in client mode to a fixed access point (or its hotspot to a fixed laptop), same room, line of sight, at 1/3/10 m, case closed vs open. Three runs each: RSSI (`iw dev wlan0 link`) and TCP throughput (`iperf3`, 30 s, both directions) | **TBD: the user sets the pass level.** Record the closed-minus-open loss | `Pi Wi-Fi` |

## Step 8: destructive (last, on a board declared sacrificial, or skipped)

| # | Do | Pass | Closes |
|---|---|---|---|
| 8.1 | Reversed 5.25 V plug, 10 s | `+5V` 0 V; D1 off; step 5.1 still passes afterwards | `eFuse model` (reverse) |
| 8.2 | Reversed 12 V adapter, 10 s | `+5V` 0 V; D1 off; steps 4.2, 5.1 and 5.5 still pass afterwards | `Reversed 12 V adapter` |
| 8.3 | Repeated current-limit retries: 2.5 A CC e-load for 60 s with `LED_EN` low, supply ≥ 3 A | Retry pulses about 110 ms apart, each ≤ 1.6 ms (record both); U74 case ≤ **100 °C**, steady after 60 s (thermocouple or IR; 25 °C margin to the 125 °C recommended TJ); afterwards 4.2, 5.1 and 5.5 still pass | `eFuse model` (heating) |
| 8.4 | Optional. Pi fitted with a **sacrificial SD card**, test firmware that overrides the cap and commands one full-white frame about 30 s after boot. Scope `+5V`, `LED_EN` and F1's voltage | Record which happens: `+5V` sags to about 3 V while U74 limits, or U74 opens within 1.6 ms and retries after 110 ms (the Pi browns out either way). Expect ≤ 0.025 A²s per event in F1 (4.7 %) [simulated]. The board recovers to a normal boot, and 5.7 still passes | `eFuse model` (system overload) |

## Not closed by bench

`EN at the surge clamp` is a part-change check: re-run the calculation if D1 changes. It
has no bench step.

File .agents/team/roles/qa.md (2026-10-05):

# QA — independent verification

Read the affected package README and `.agents/team/team.md` before verifying the assigned
acceptance criteria on final code/inputs. Review the developer/engineer/test-engineer
handoff; confirm its revision/diff before reusing results. QA verifies behavior independently,
while test engineer authors fixtures/harnesses; request missing test states through lead.
Read-only implementation scope unless lead explicitly assigns a test/documentation path.

Choose evidence appropriate to risk: portable Rust tests, production runtime E2E/button/
display behavior, shared contract/dimension checks, native ERC/DRC/parity and SPICE, CAD
mesh/assembly views, Linux VM, AArch64 linkage or Yocto metadata. Do not duplicate every
check. Obtain ownership before heavy generation, Docker/QEMU or image tasks; report exact
commands, inputs, artifacts/results and remaining limitations. Validate negative/startup/
fault cases and peer interface contracts, not just a successful screenshot.

Never substitute simulation/render/check output for bench measurements or printed fit.
Physical release evidence, Pi flashing, vendor uploads and electrical experiments require
explicit authorization and appropriate engineering guidance. Never reset user data or
relax a gate for a demo. Send one evidence-based report to lead; reviewers reuse it.

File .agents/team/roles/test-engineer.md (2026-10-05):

# Test engineer — regression harnesses and reproducible fixtures (on demand)

Read the owning package README and test recipes, plus `apps/firmware/README.md` for
runtime/Linux tests, `hardware/pcb/README.md` for SPICE, or `hardware/cad/README.md` for
mesh/dimension checks. Build assigned automated tests and fixtures; QA independently
verifies the resulting behavior. Do not create a second implementation to test itself.

Use the production firmware runtime/harness and maintained GPIO/display/Linux simulation
interfaces, shared hardware contracts, native PCB validation and real generator outputs
as appropriate. Cover negative paths, startup/failure states, contract boundaries and
reported regressions, not snapshot volume or mirrored implementation details. Obtain
ownership of test paths and heavy check execution from lead. Do not mutate another
agent's code or the shared checkout to prove a test fails; use an isolated copy.

Record fixture inputs, code/diff identity, deterministic reproduction, observed results
and limitations. A simulated pin/button/display/SPICE outcome is not a measured circuit,
Pi integration or manufactured fit. Never invent physical/model responses, overwrite
user data, flash hardware or bypass physical-evidence gates. Send one report to lead,
then idle; QA and PR maker can reuse current evidence without rerunning it unassigned.

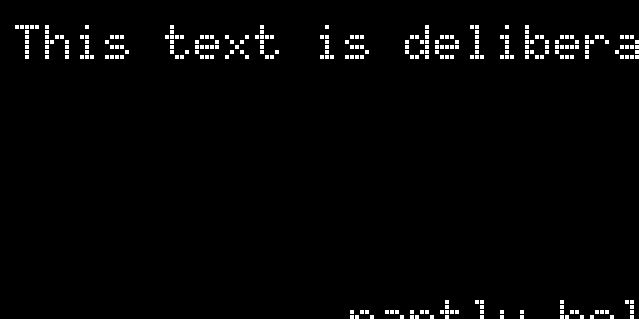
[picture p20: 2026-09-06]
apps/firmware/tests/display/screenshots/clipped-text.png

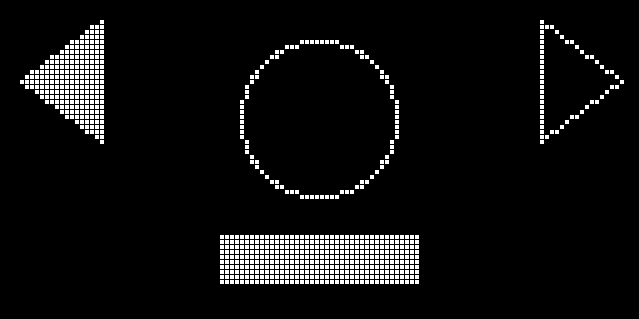
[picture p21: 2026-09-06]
apps/firmware/tests/display/screenshots/symbols.png

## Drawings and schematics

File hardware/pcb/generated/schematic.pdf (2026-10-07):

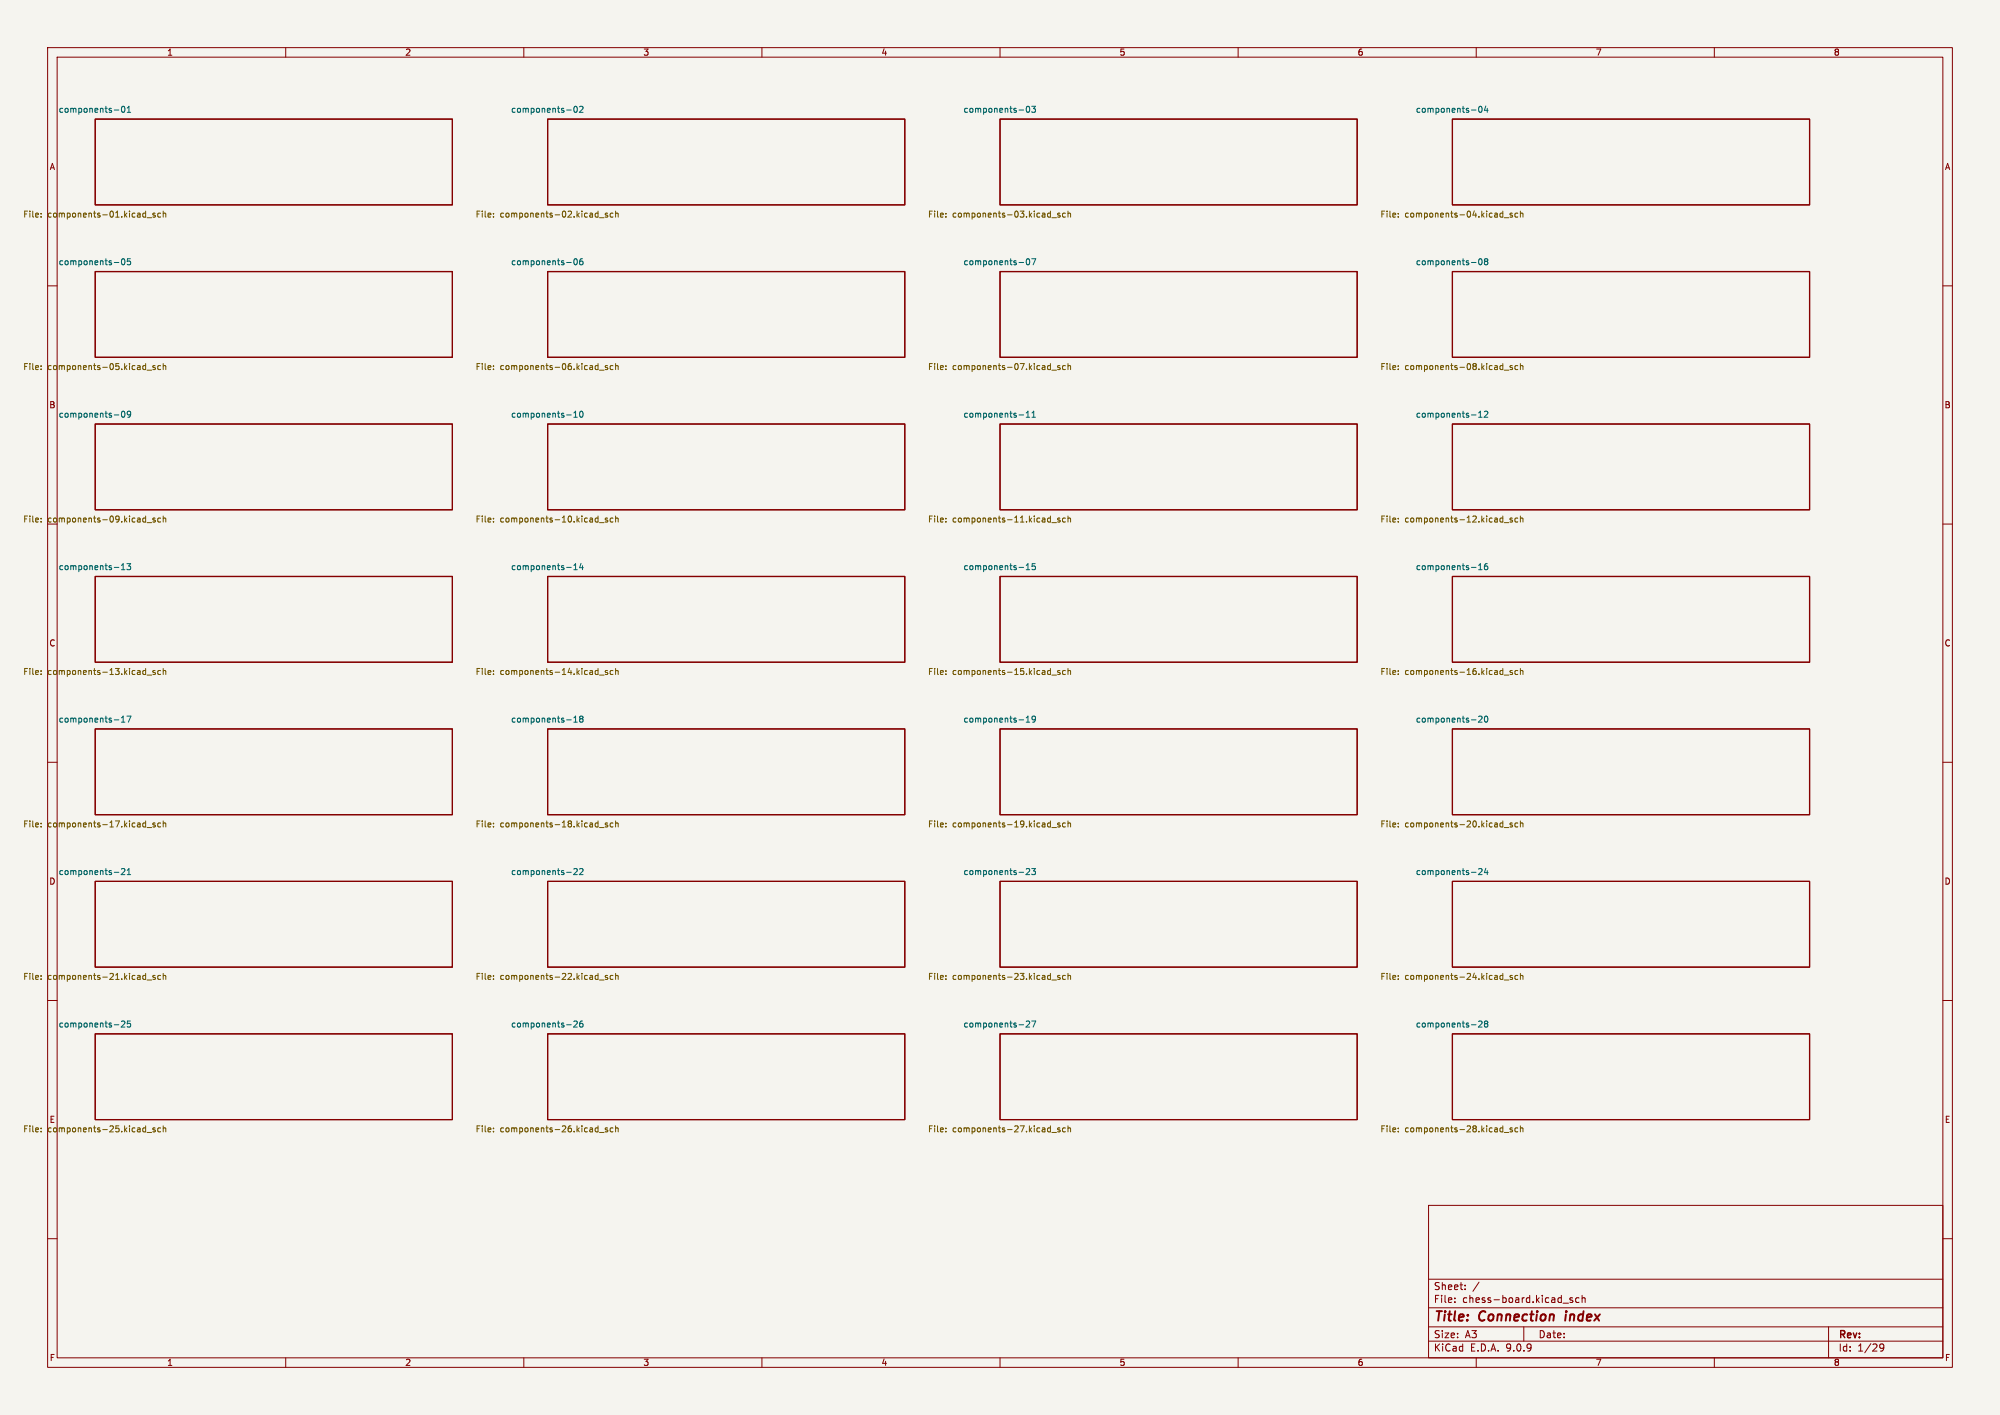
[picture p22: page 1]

File: chess-board.kicad_sch Sheet: /
Id: 1/29 Title: Connection index

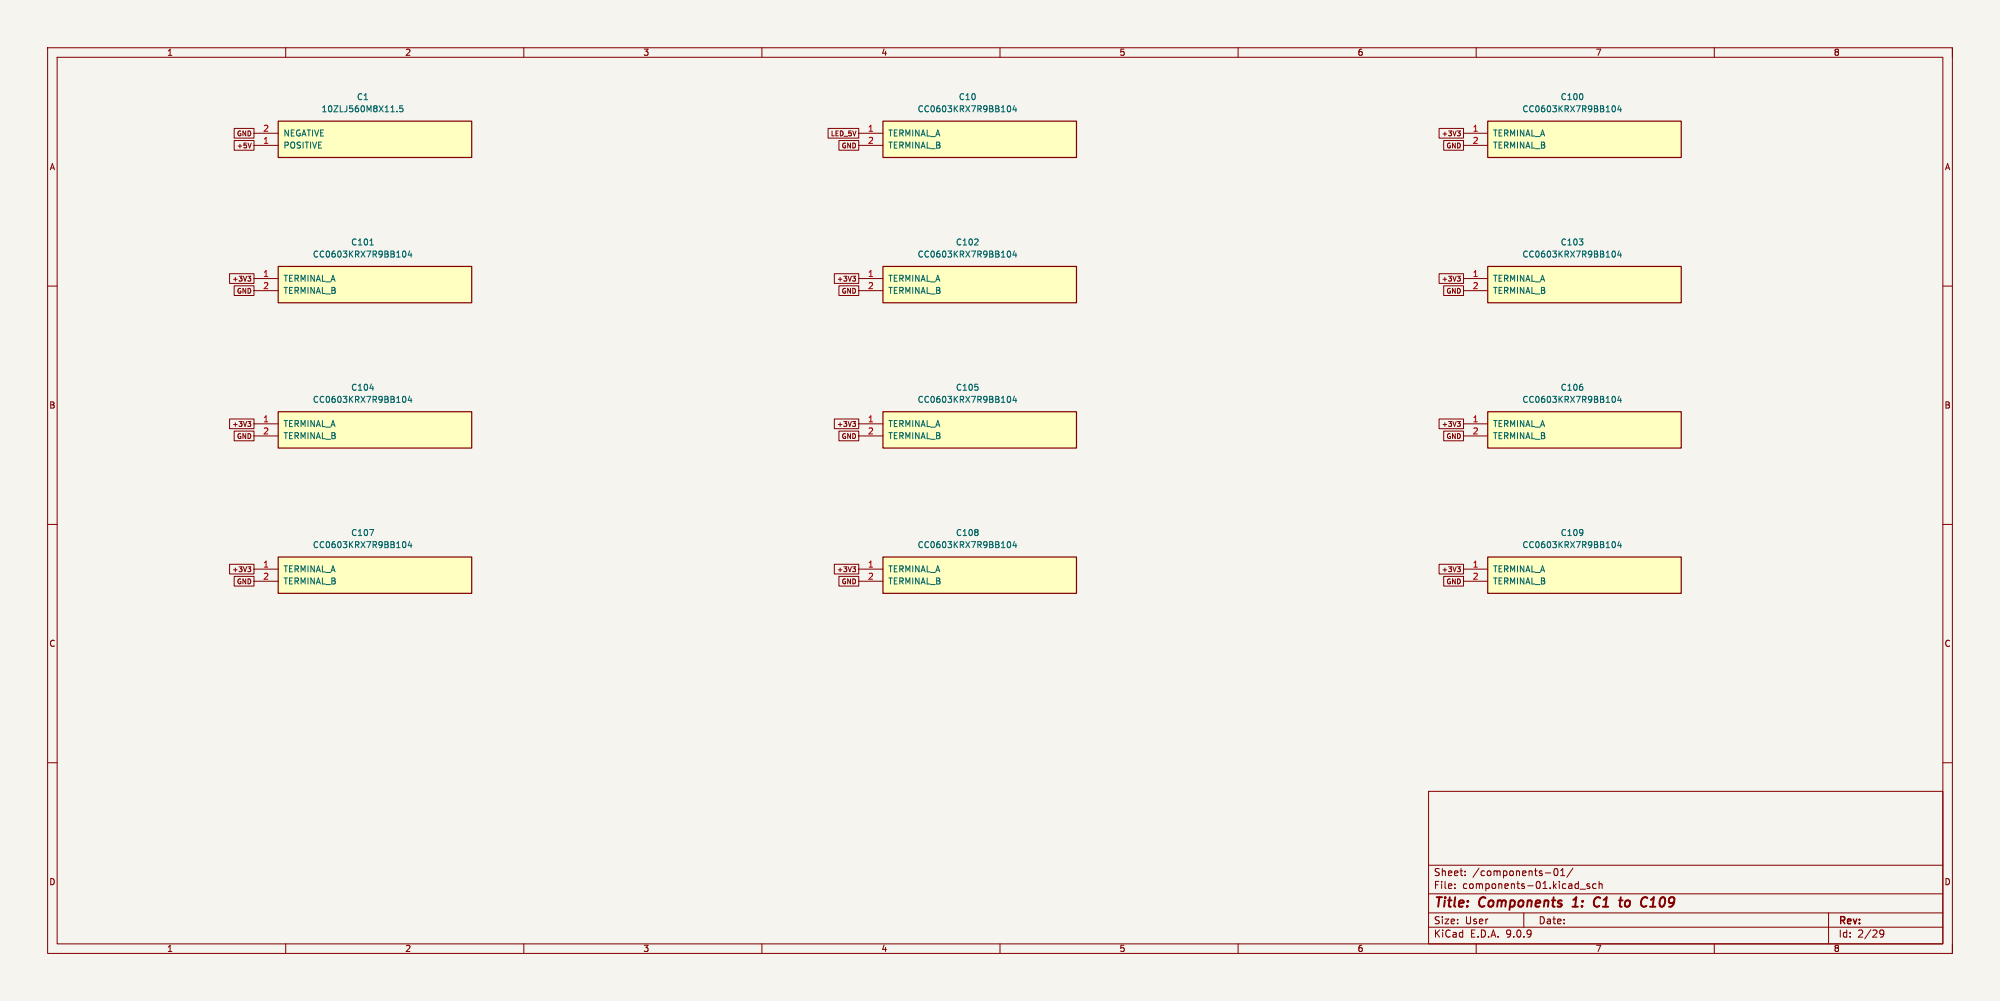
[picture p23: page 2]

File: components-01.kicad_sch Sheet: /components-01/
Id: 2/29 Title: Components 1: C1 to C109

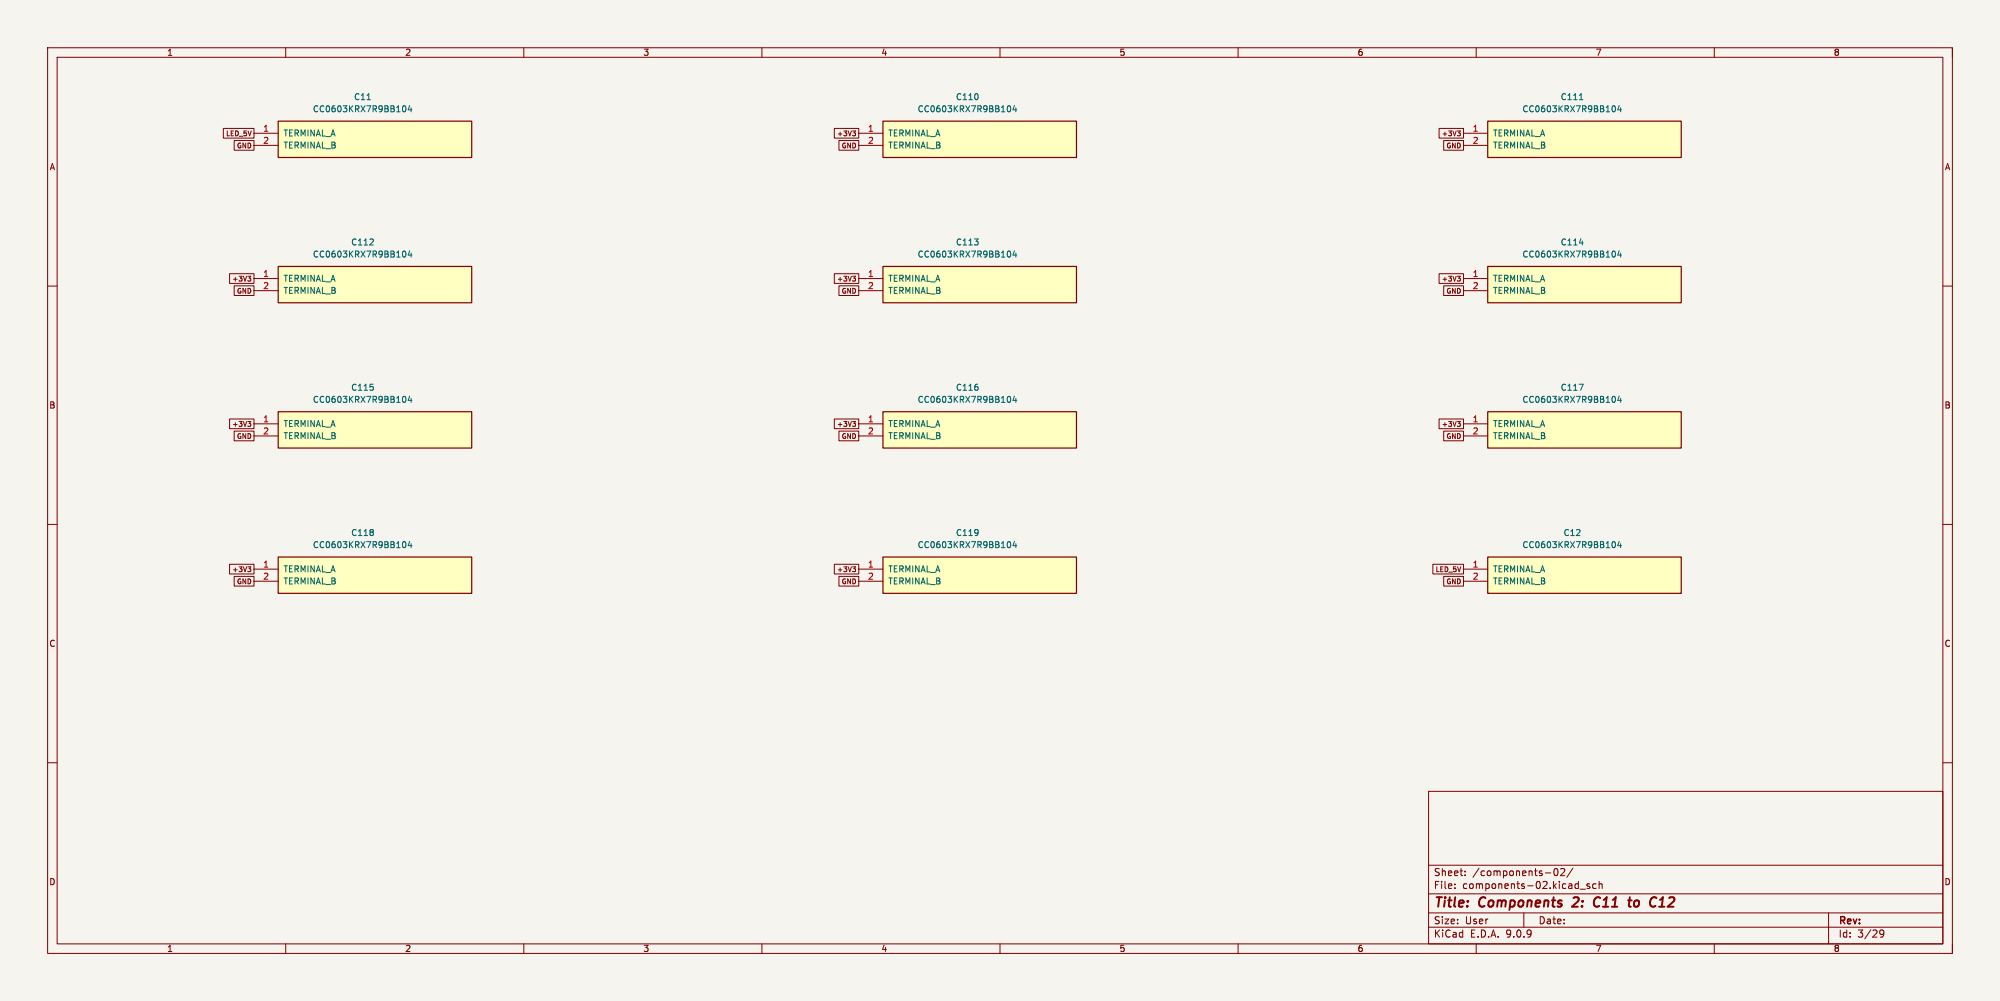
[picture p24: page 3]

File: components-02.kicad_sch Sheet: /components-02/
Id: 3/29 Title: Components 2: C11 to C12

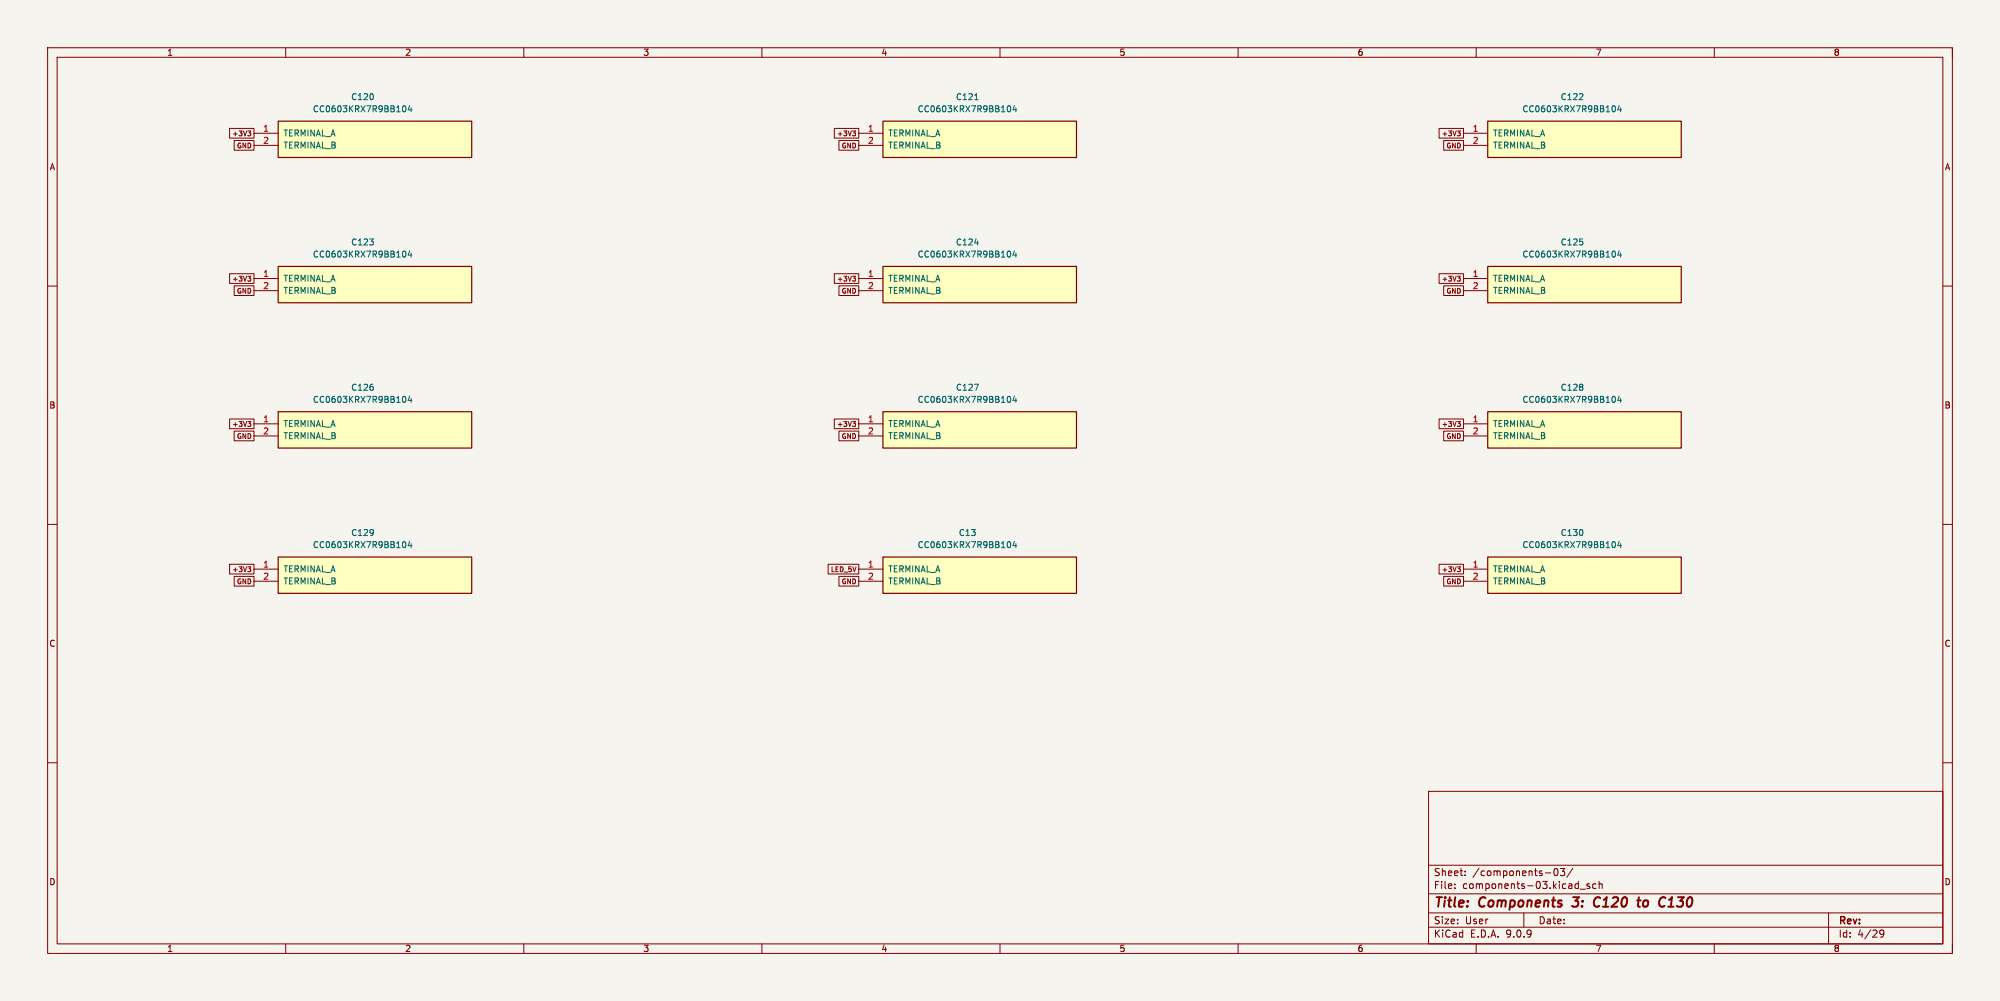
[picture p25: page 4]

File: components-03.kicad_sch Sheet: /components-03/
Id: 4/29 Title: Components 3: C120 to C130

File: components-04.kicad_sch Sheet: /components-04/
Id: 5/29 Title: Components 4: C131 to C141

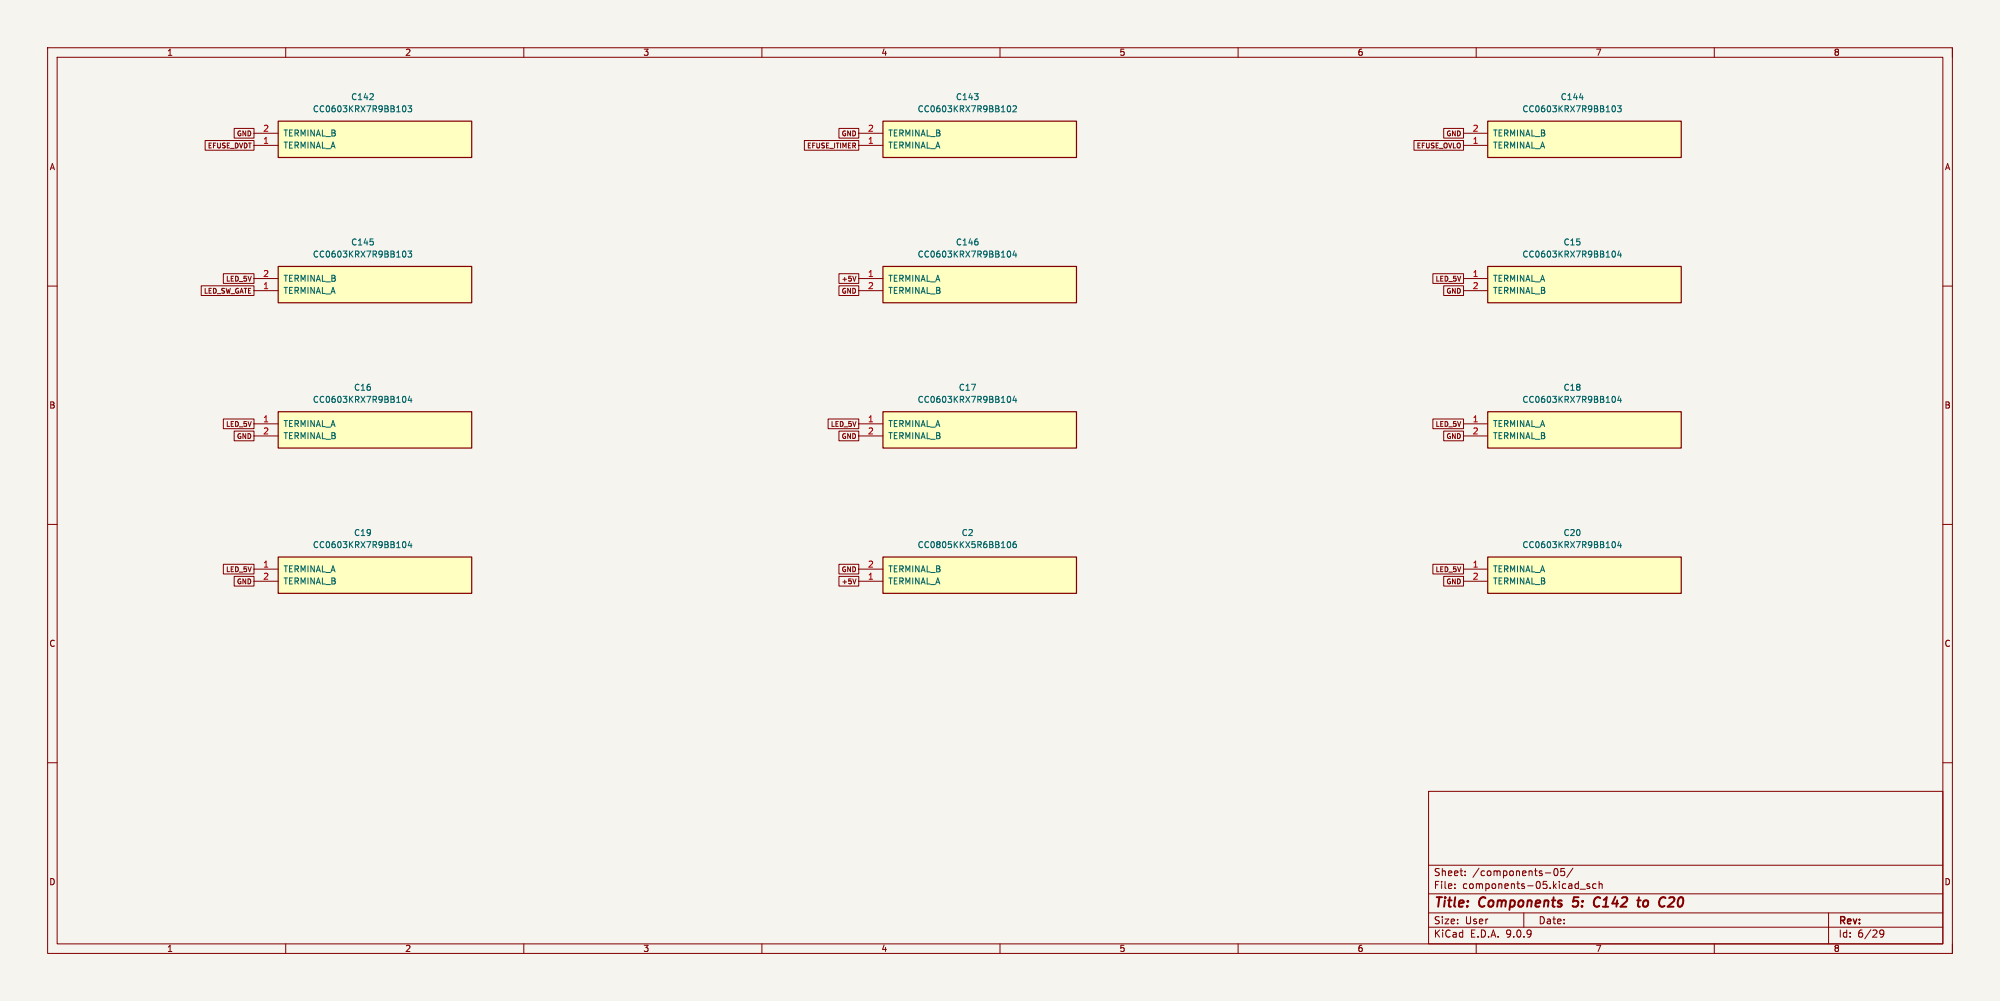
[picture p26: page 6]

File: components-05.kicad_sch Sheet: /components-05/
Id: 6/29 Title: Components 5: C142 to C20

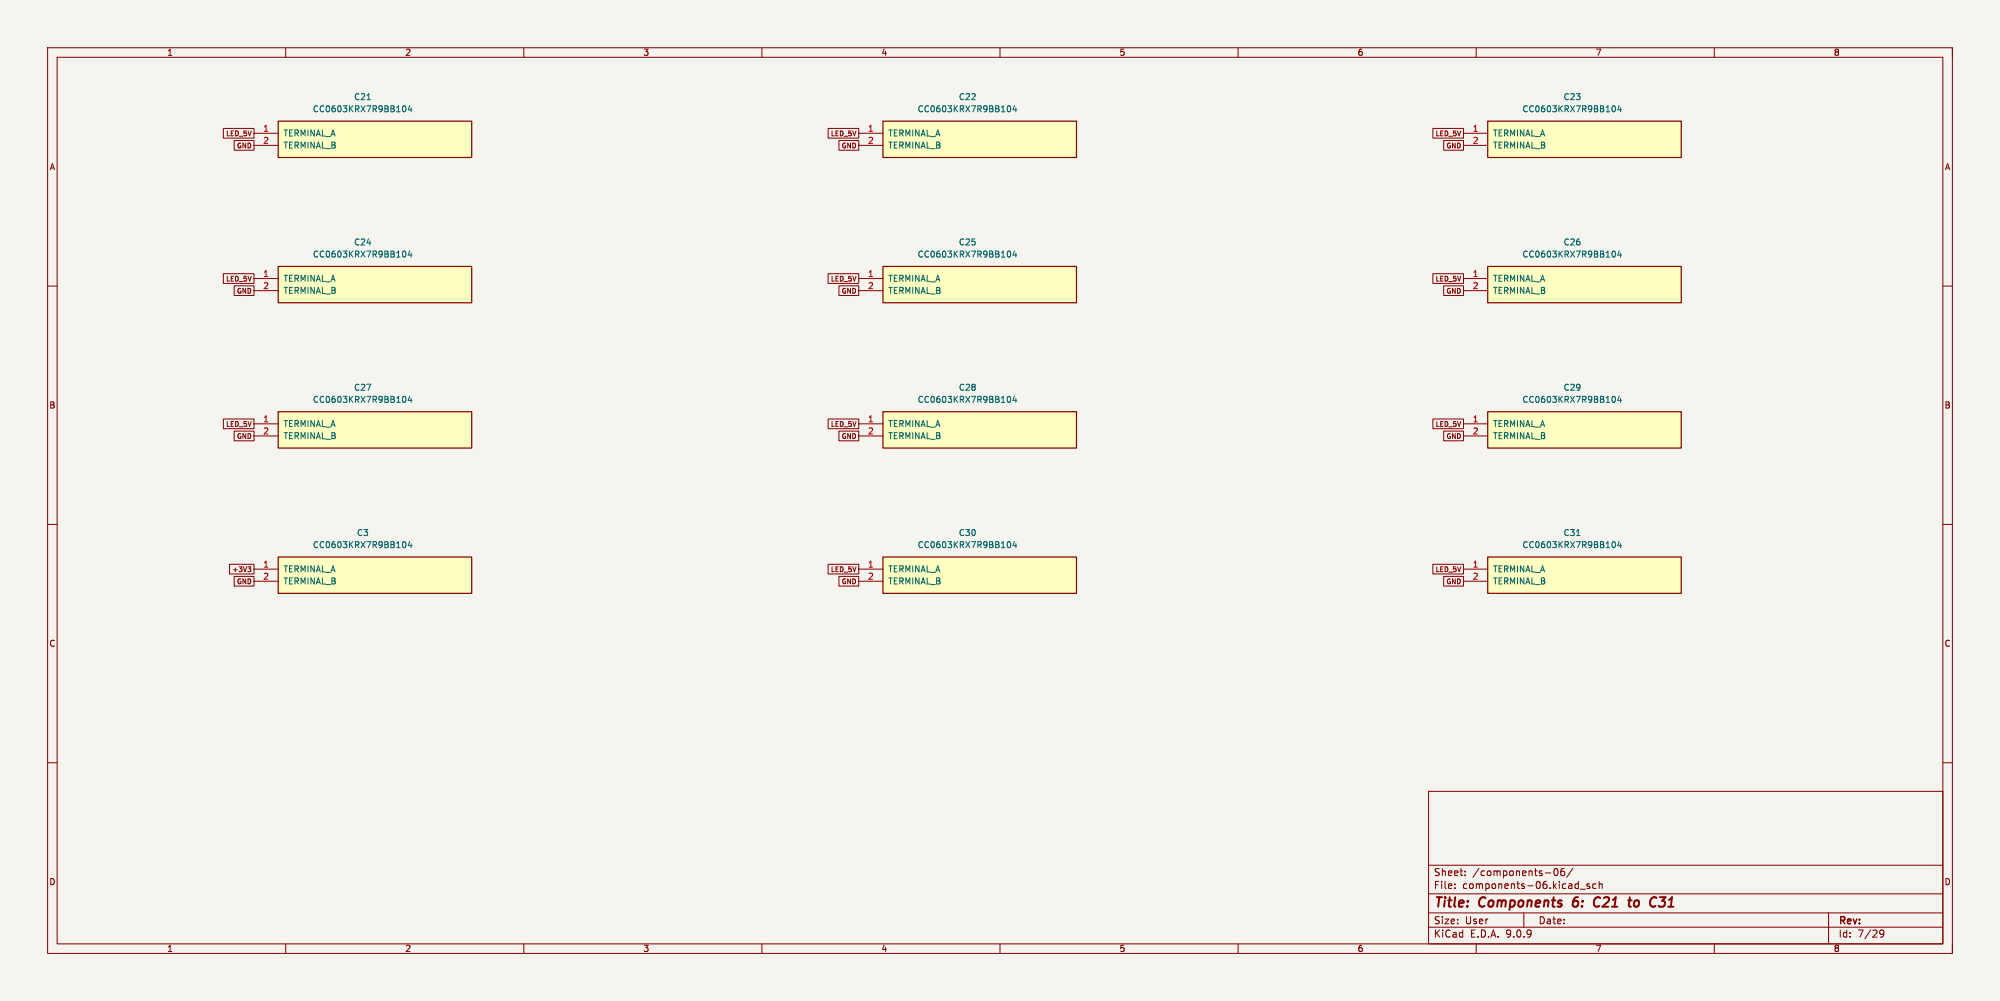
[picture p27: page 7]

File: components-06.kicad_sch Sheet: /components-06/
Id: 7/29 Title: Components 6: C21 to C31

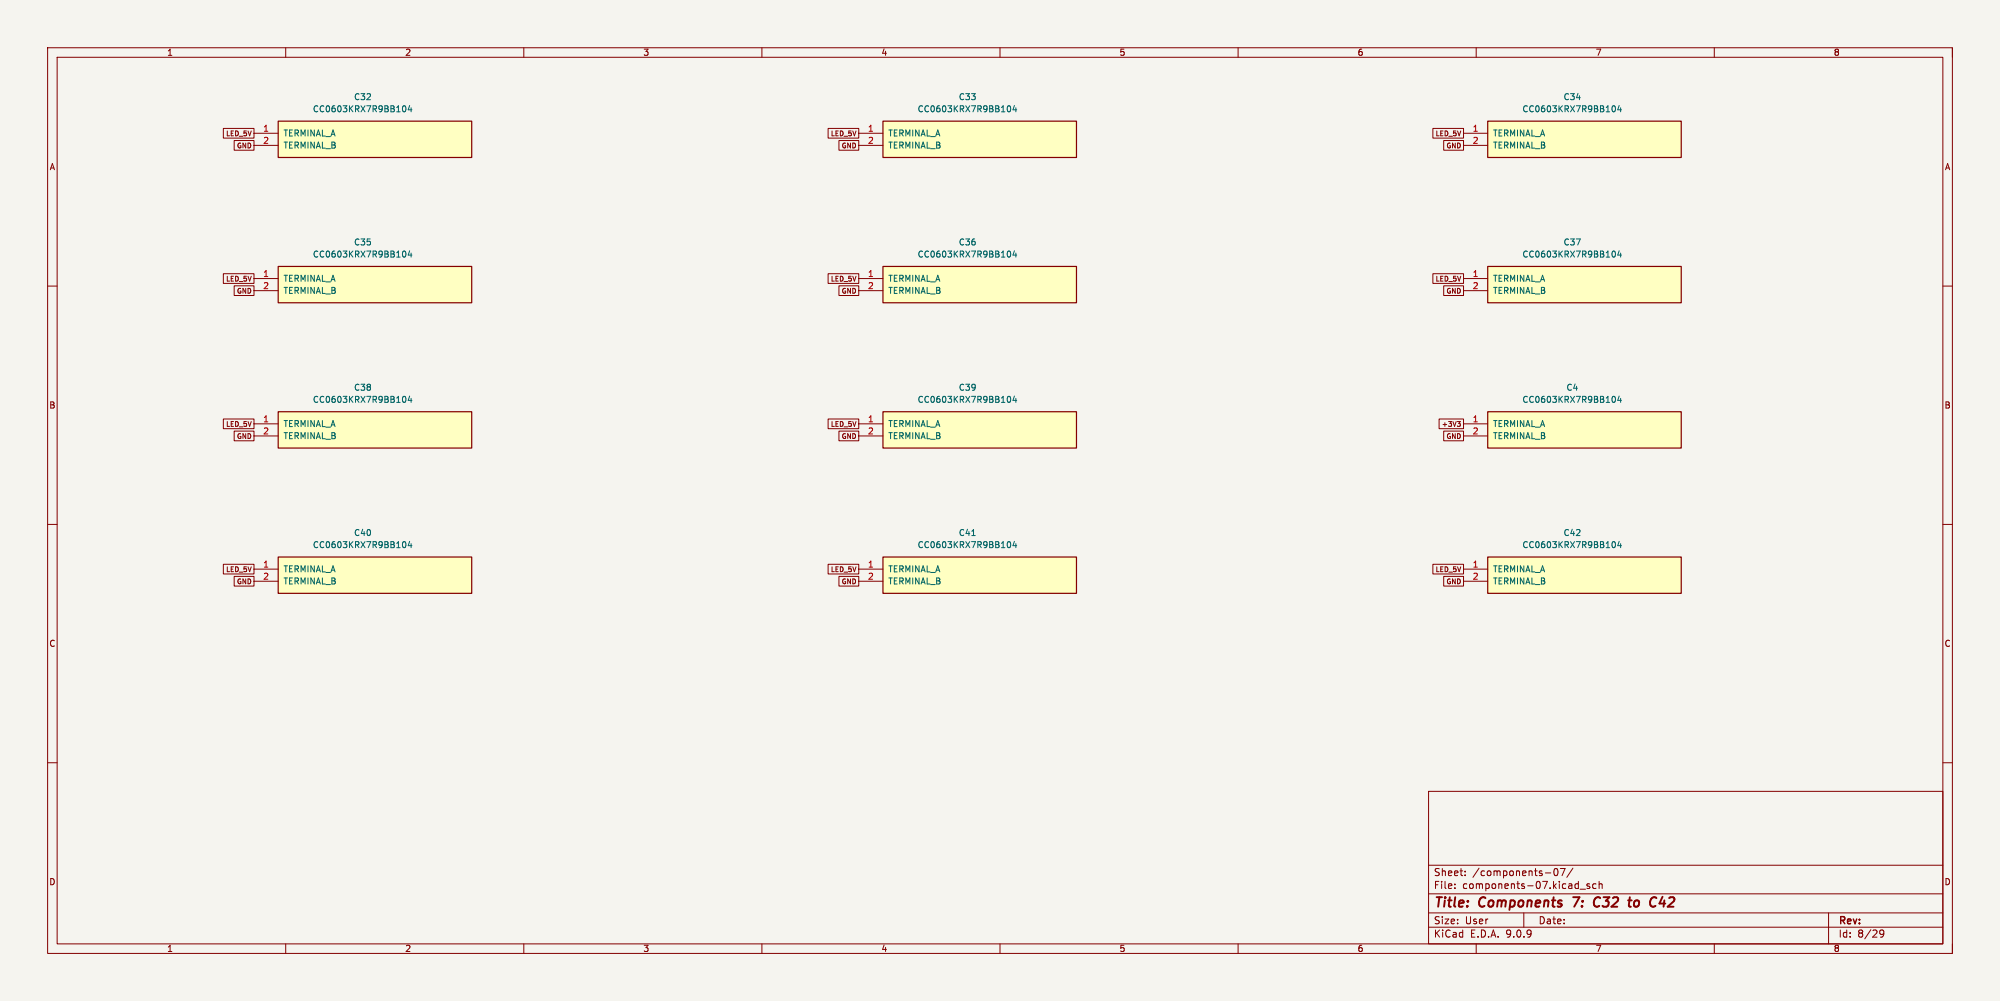
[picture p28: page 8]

File: components-07.kicad_sch Sheet: /components-07/
Id: 8/29 Title: Components 7: C32 to C42

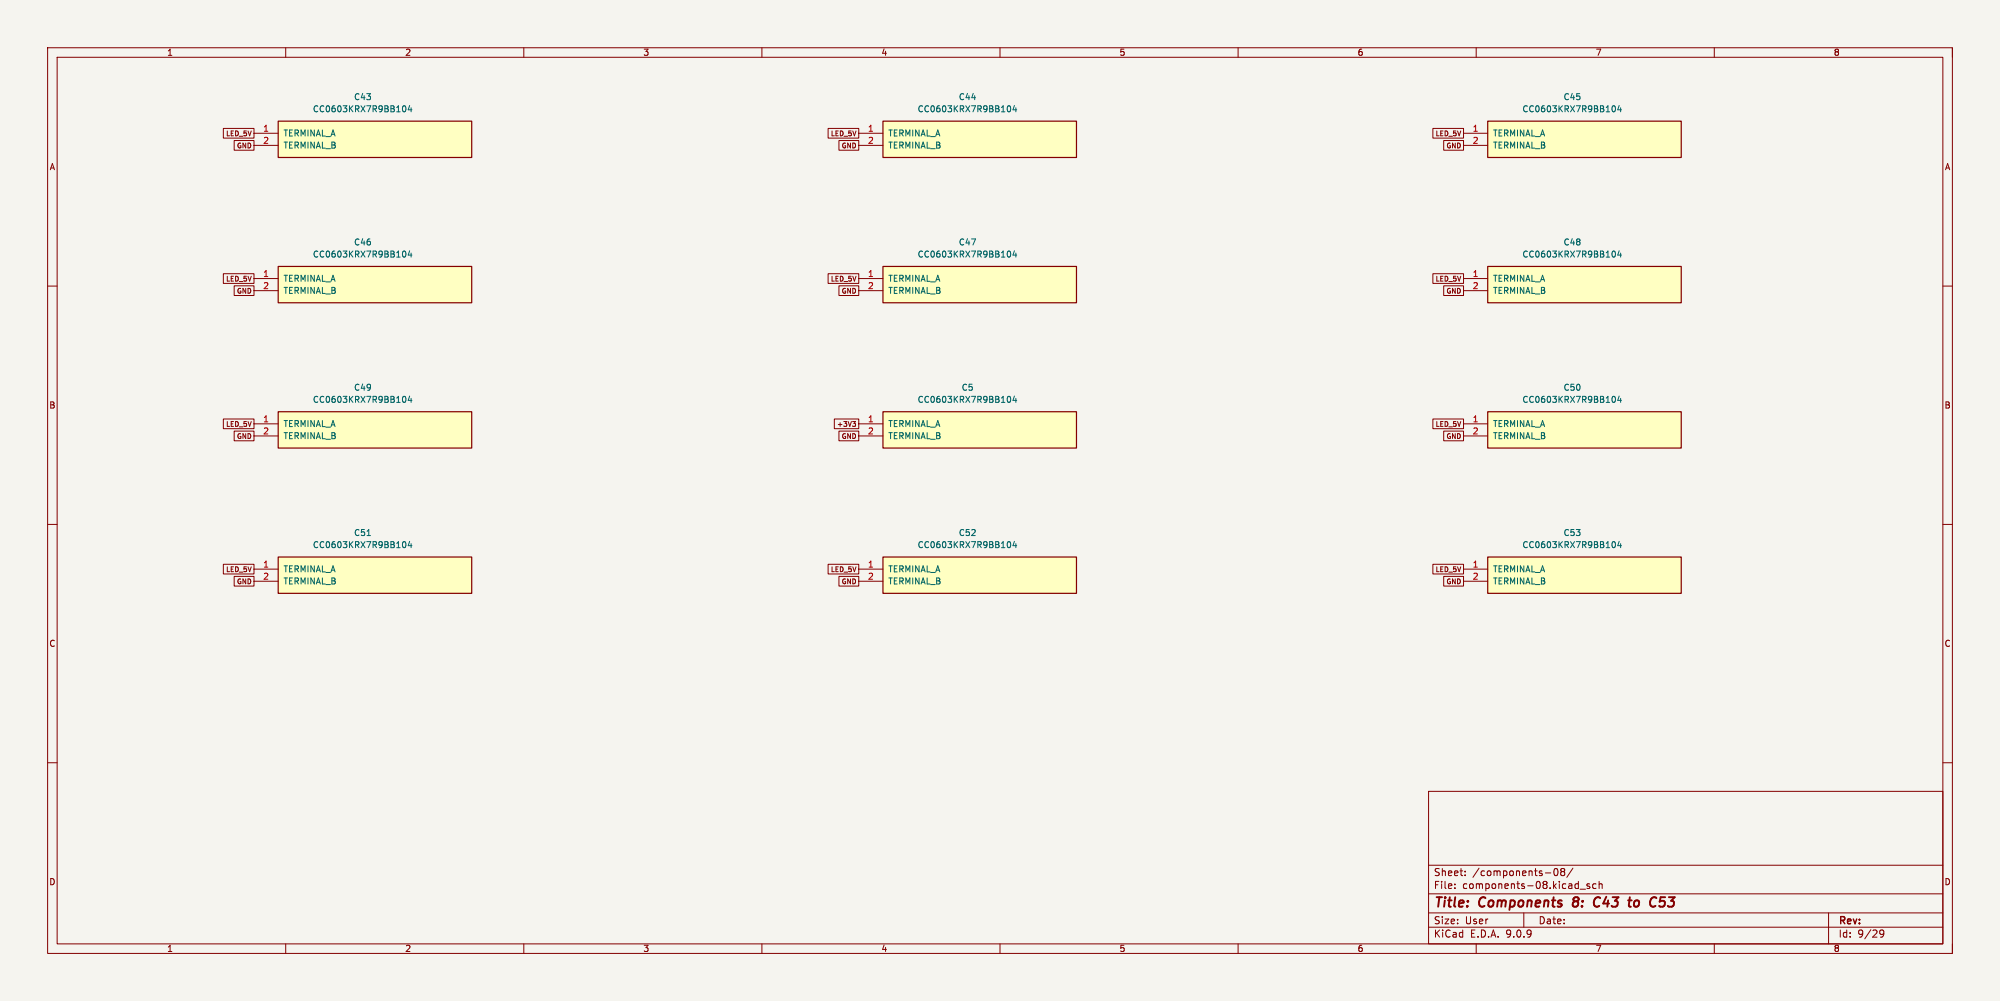
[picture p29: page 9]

File: components-08.kicad_sch Sheet: /components-08/
Id: 9/29 Title: Components 8: C43 to C53

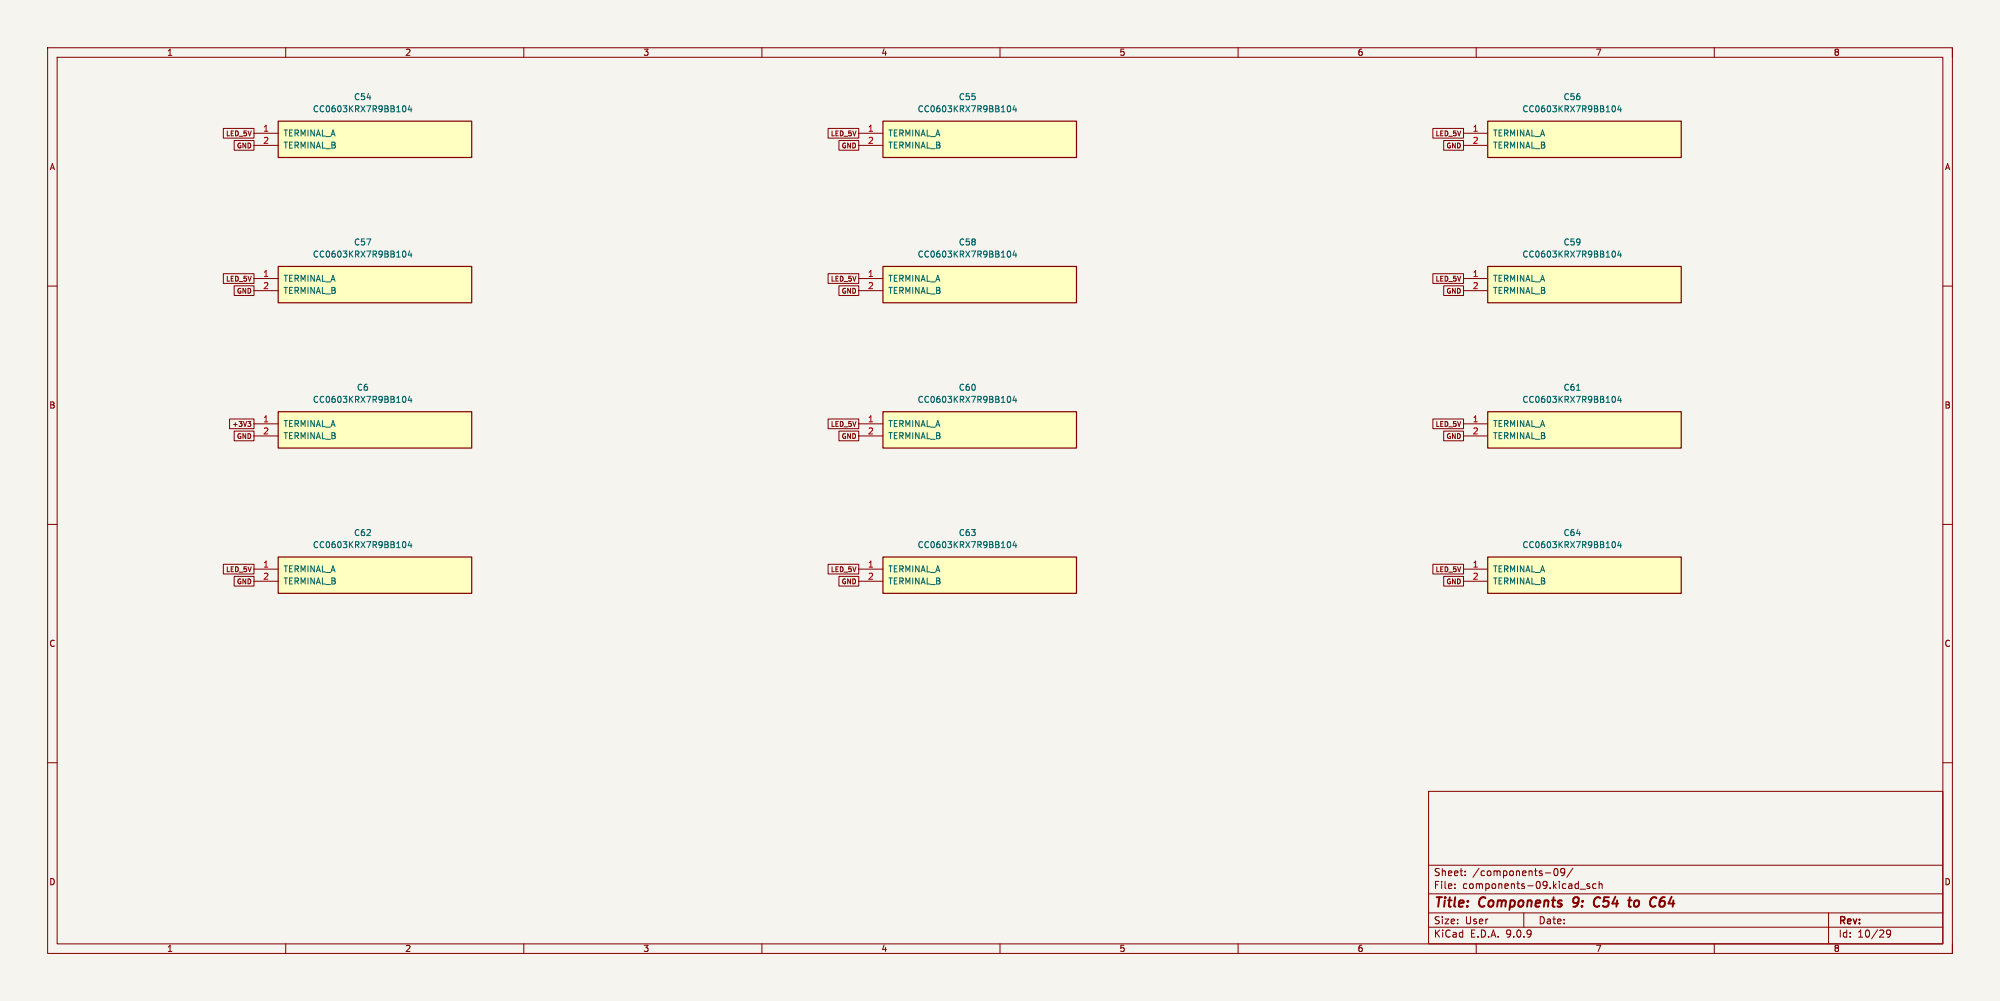
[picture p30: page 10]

File: components-09.kicad_sch Sheet: /components-09/
Id: 10/29 Title: Components 9: C54 to C64

File: components-10.kicad_sch Sheet: /components-10/
Id: 11/29 Title: Components 10: C65 to C75

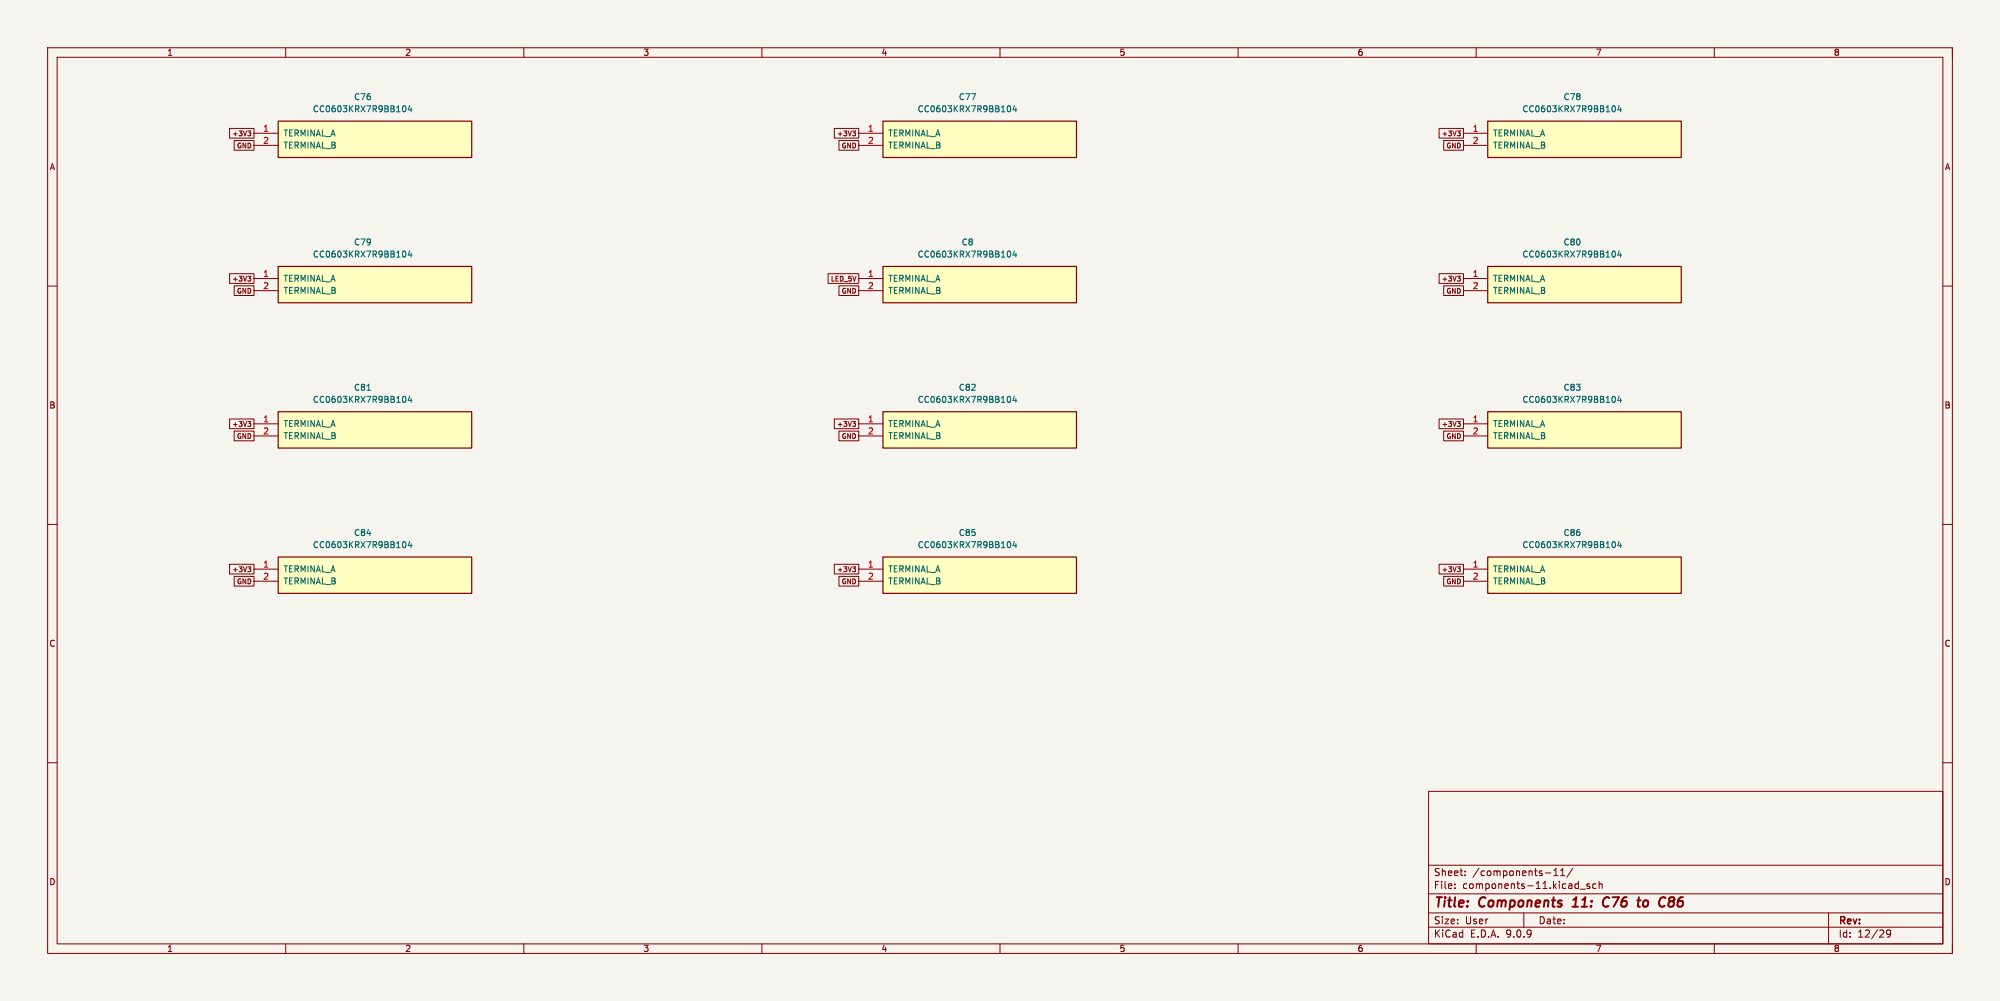
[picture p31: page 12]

File: components-11.kicad_sch Sheet: /components-11/
Id: 12/29 Title: Components 11: C76 to C86

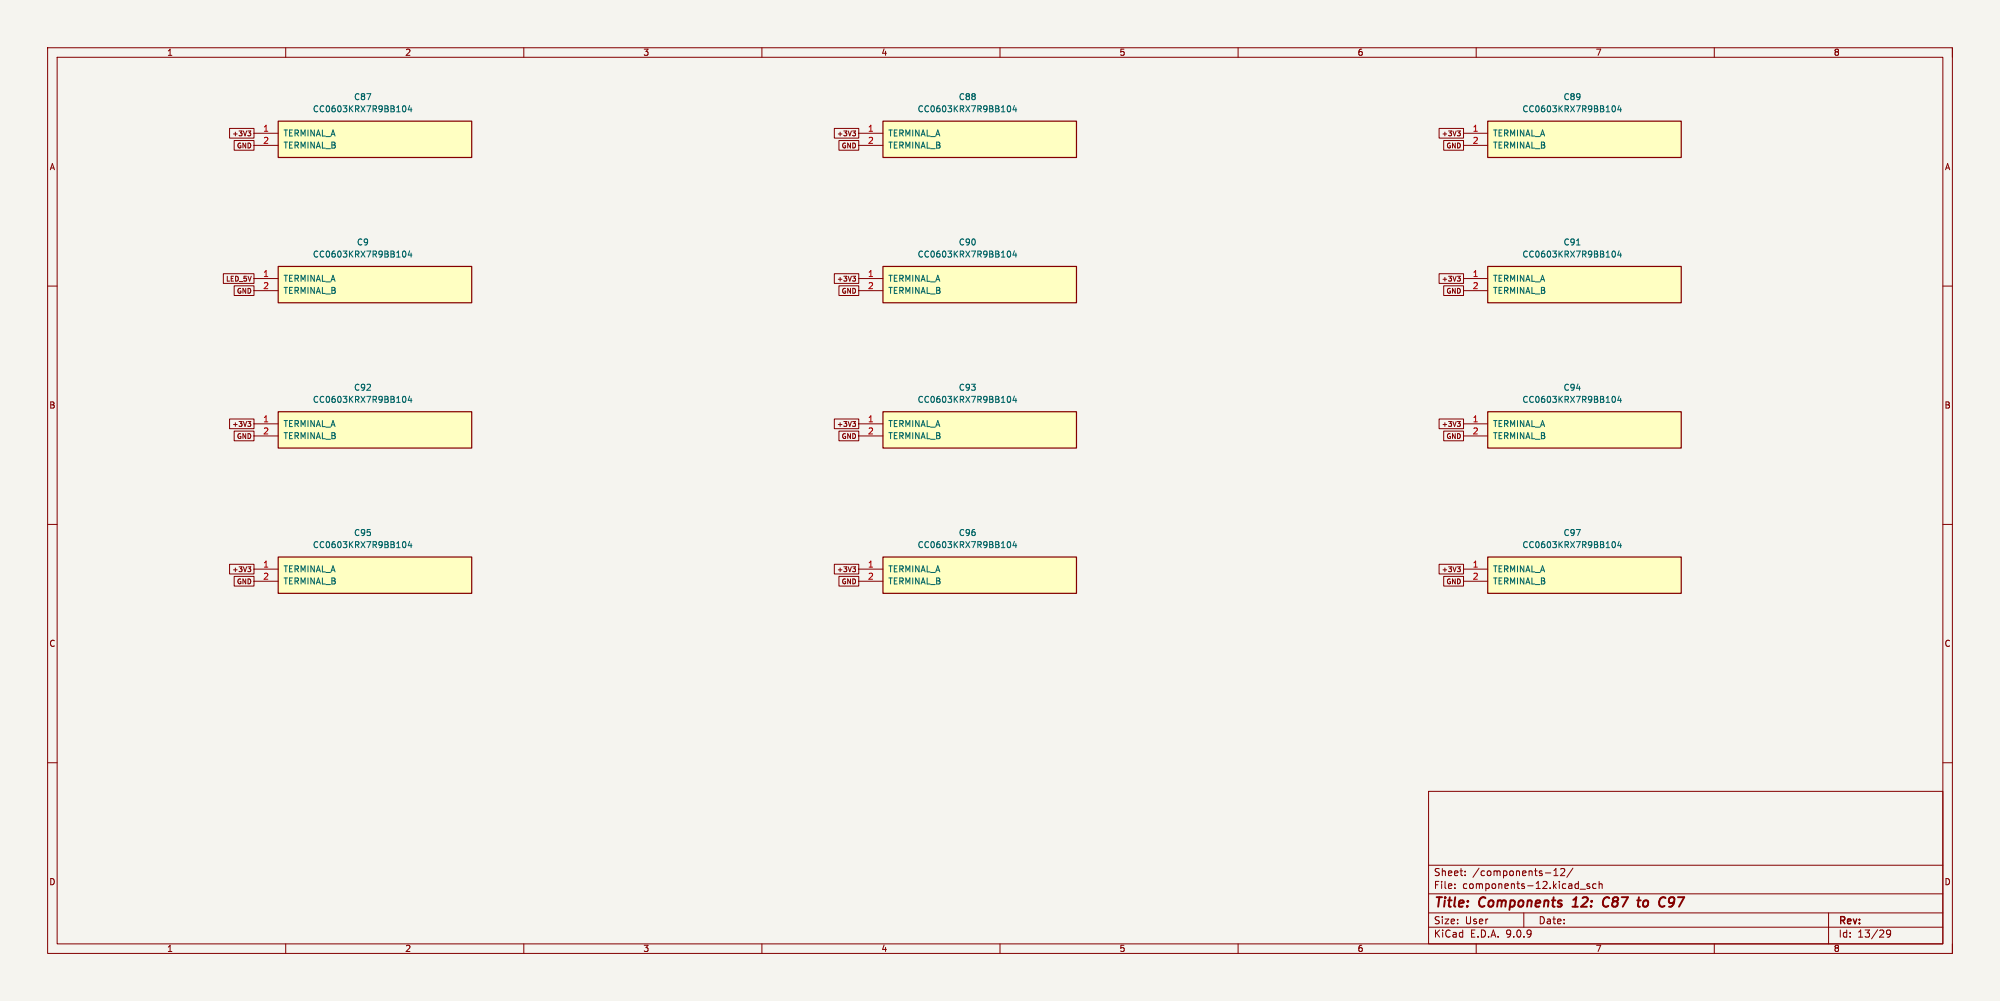
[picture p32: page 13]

File: components-12.kicad_sch Sheet: /components-12/
Id: 13/29 Title: Components 12: C87 to C97

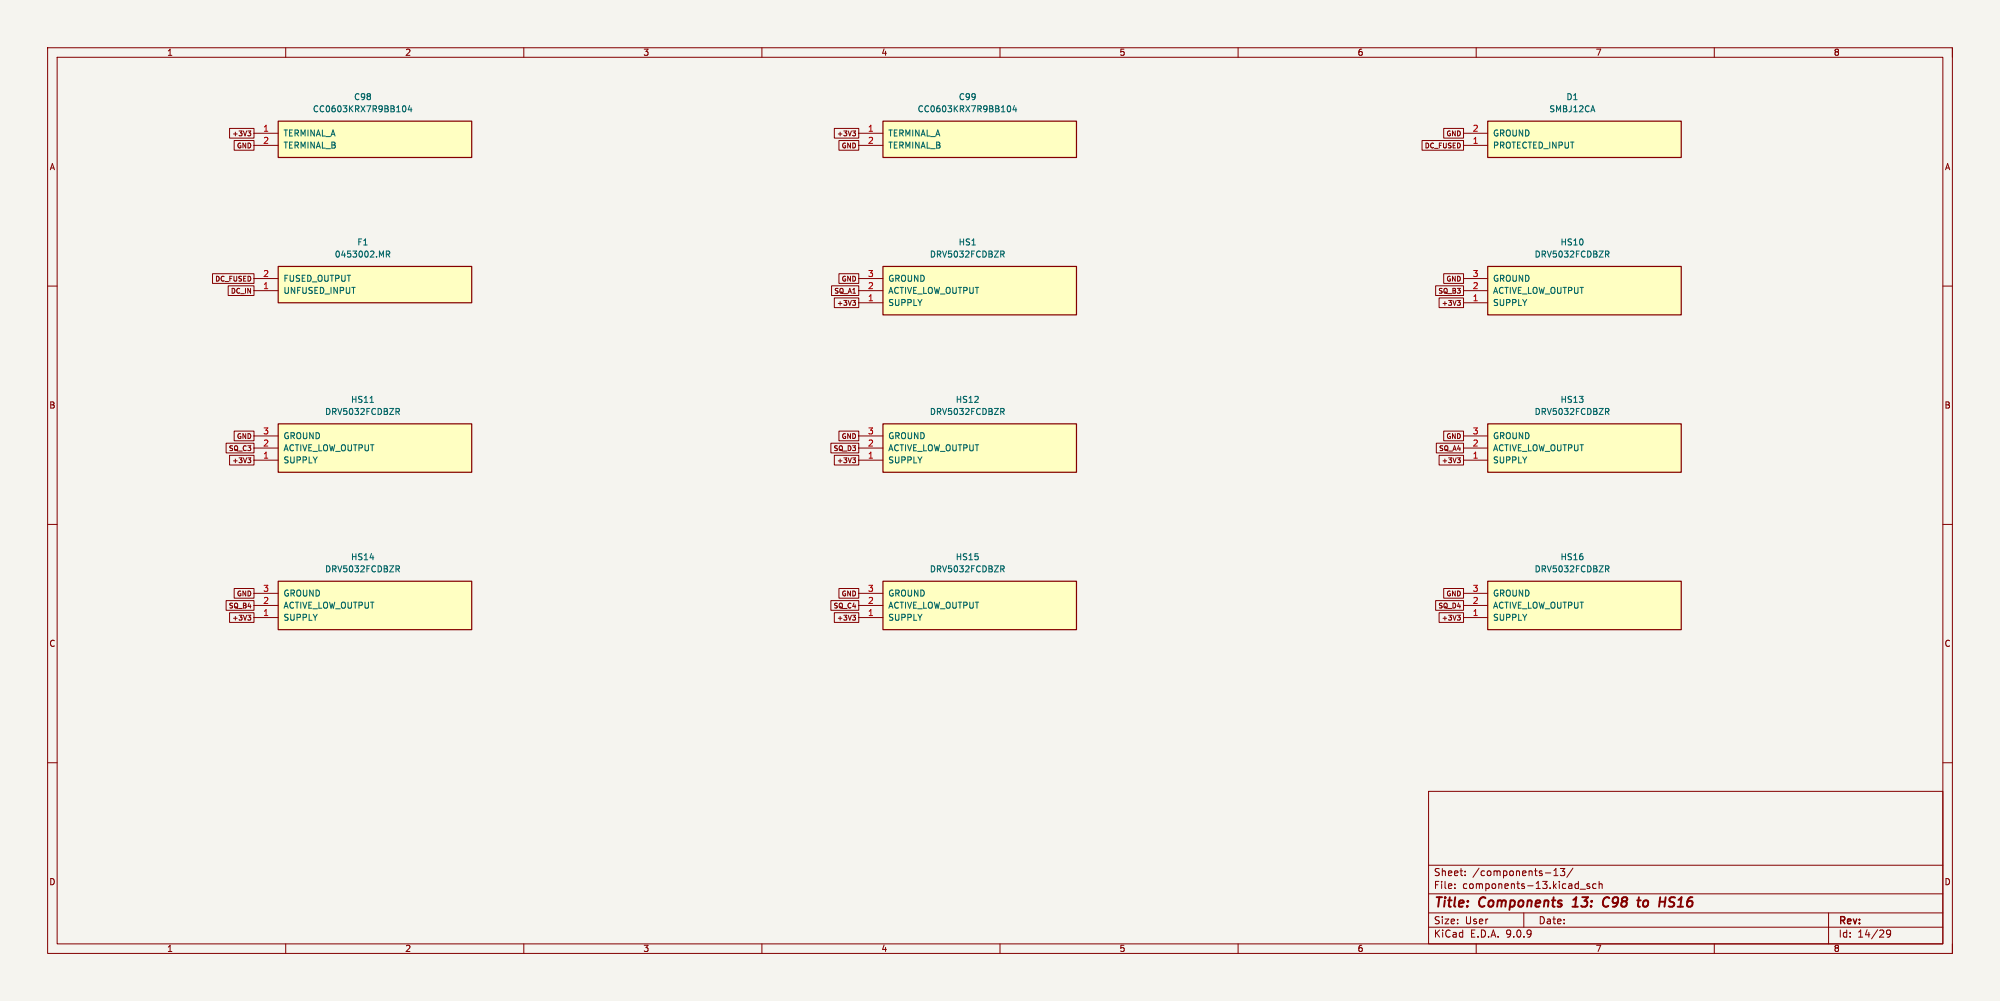
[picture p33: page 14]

Id: 14/29 Title: Components 13: C98 to HS16


File: components-14.kicad_sch Sheet: /components-14/
Id: 15/29 Title: Components 14: HS17 to HS27

File: components-15.kicad_sch Sheet: /components-15/
Id: 16/29 Title: Components 15: HS28 to HS38


Id: 17/29 Title: Components 16: HS39 to HS49


File: components-17.kicad_sch Sheet: /components-17/
Id: 18/29 Title: Components 17: HS5 to HS6


Id: 19/29 Title: Components 18: HS60 to Q1


File: components-19.kicad_sch Sheet: /components-19/
Id: 20/29 Title: Components 19: Q2 to R4

Id: 21/29 Title: Components 20: R5 to SW4


File: components-21.kicad_sch Sheet: /components-21/
Id: 22/29 Title: Components 21: SW5 to TP7


File: components-22.kicad_sch Sheet: /components-22/
Id: 23/29 Title: Components 22: U1 to U2


File: components-23.kicad_sch Sheet: /components-23/
Id: 24/29 Title: Components 23: U20 to U30


File: components-24.kicad_sch Sheet: /components-24/
Id: 25/29 Title: Components 24: U31 to U41


File: components-25.kicad_sch Sheet: /components-25/
Id: 26/29 Title: Components 25: U42 to U52

Id: 27/29 Title: Components 26: U53 to U63


File: components-27.kicad_sch Sheet: /components-27/
Id: 28/29 Title: Components 27: U64 to U74


File: components-28.kicad_sch Sheet: /components-28/
Id: 29/29 Title: Components 28: U75 to U9

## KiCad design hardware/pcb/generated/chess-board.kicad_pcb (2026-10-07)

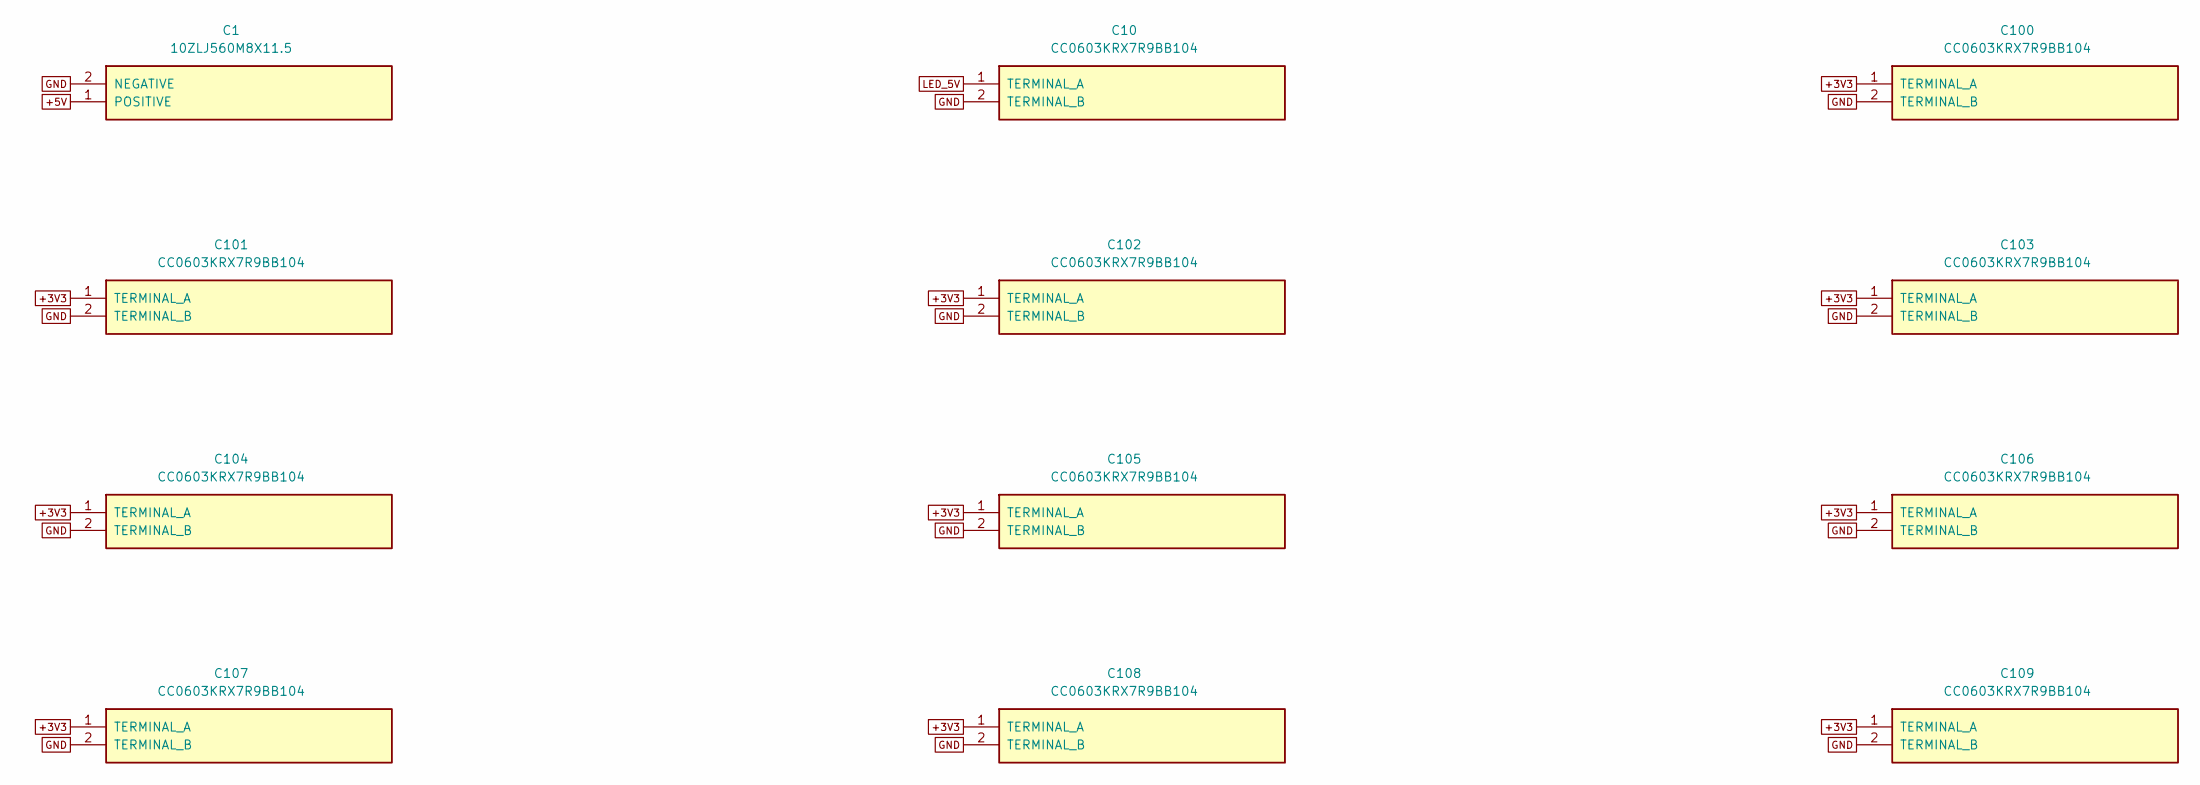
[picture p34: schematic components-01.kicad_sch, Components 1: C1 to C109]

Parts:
C1: 10ZLJ560M8X11.5; CAP_560U
C10, C100, C101, C102, C103, C104, C105, C106, C107, C108, C109: CC0603KRX7R9BB104; CAP_100N

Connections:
+3V3: C100.1 (TERMINAL_A), C101.1 (TERMINAL_A), C102.1 (TERMINAL_A), C103.1 (TERMINAL_A), C104.1 (TERMINAL_A), C105.1 (TERMINAL_A), C106.1 (TERMINAL_A), C107.1 (TERMINAL_A), C108.1 (TERMINAL_A), C109.1 (TERMINAL_A); also elsewhere on the board
+5V: C1.1 (POSITIVE); also elsewhere on the board
GND: C1.2 (NEGATIVE), C10.2 (TERMINAL_B), C100.2 (TERMINAL_B), C101.2 (TERMINAL_B), C102.2 (TERMINAL_B), C103.2 (TERMINAL_B), C104.2 (TERMINAL_B), C105.2 (TERMINAL_B), C106.2 (TERMINAL_B), C107.2 (TERMINAL_B), C108.2 (TERMINAL_B), C109.2 (TERMINAL_B); also elsewhere on the board
LED_5V: C10.1 (TERMINAL_A); also elsewhere on the board

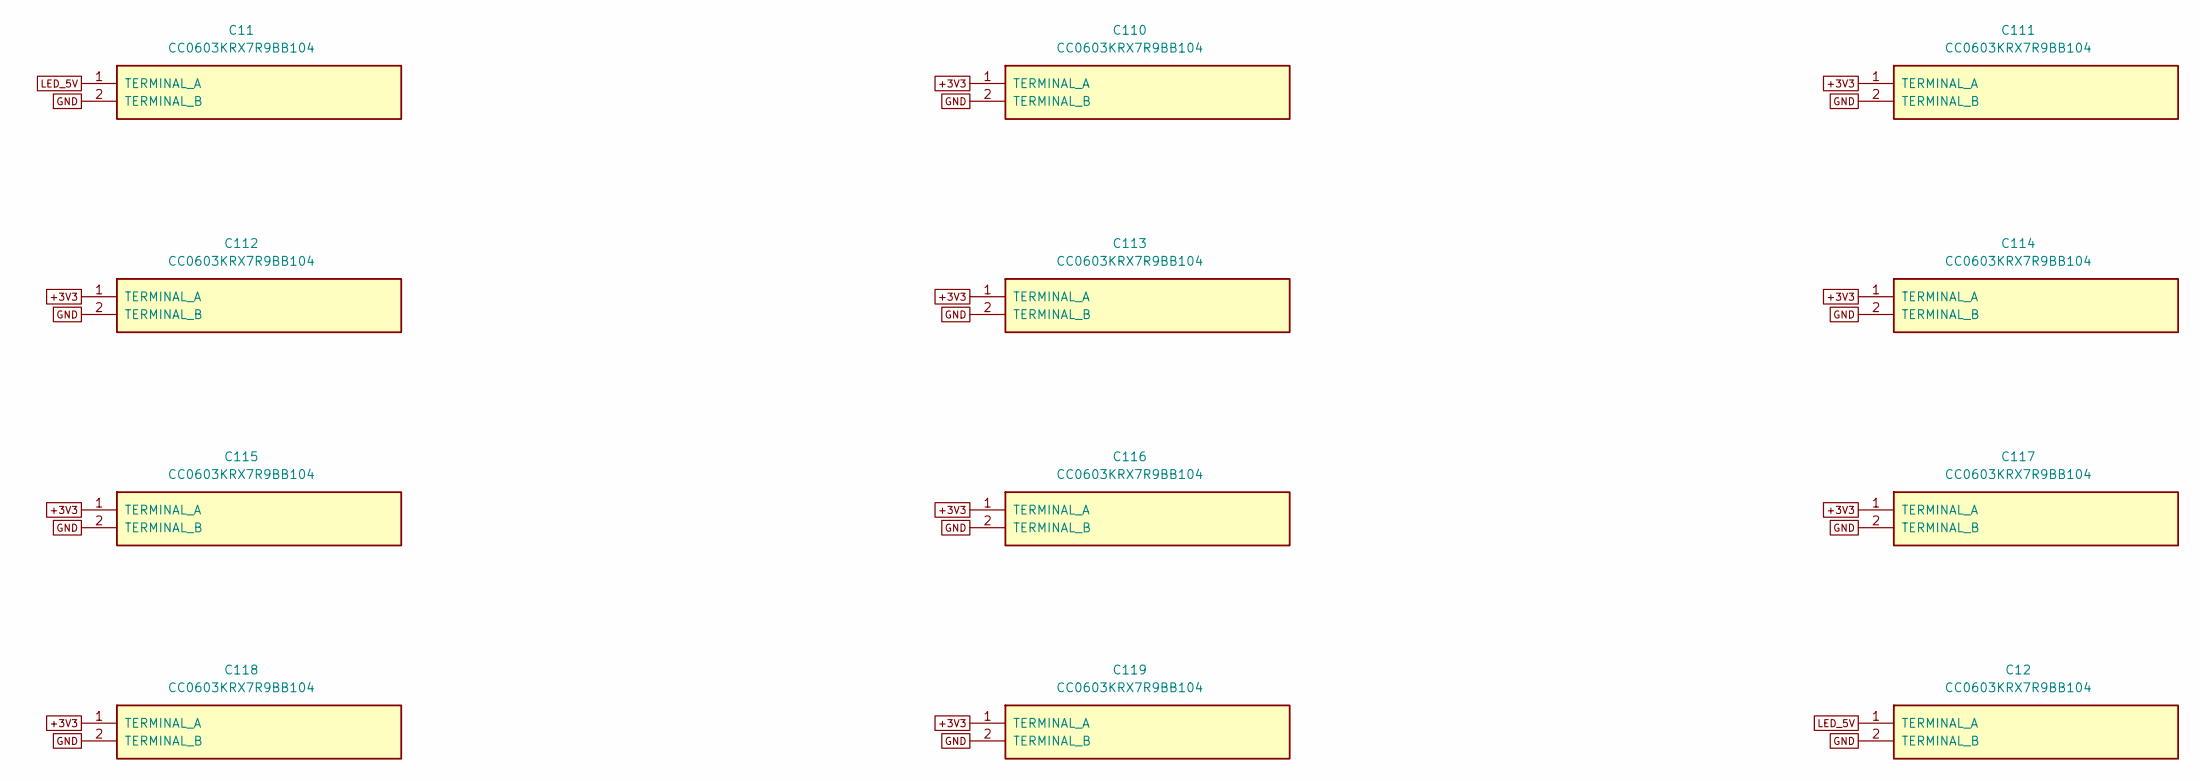
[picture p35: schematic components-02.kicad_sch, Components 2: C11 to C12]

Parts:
C11, C12, C110, C111, C112, C113, C114, C115, C116, C117, C118, C119: CC0603KRX7R9BB104; CAP_100N

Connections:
+3V3: C110.1 (TERMINAL_A), C111.1 (TERMINAL_A), C112.1 (TERMINAL_A), C113.1 (TERMINAL_A), C114.1 (TERMINAL_A), C115.1 (TERMINAL_A), C116.1 (TERMINAL_A), C117.1 (TERMINAL_A), C118.1 (TERMINAL_A), C119.1 (TERMINAL_A); also elsewhere on the board
GND: C11.2 (TERMINAL_B), C12.2 (TERMINAL_B), C110.2 (TERMINAL_B), C111.2 (TERMINAL_B), C112.2 (TERMINAL_B), C113.2 (TERMINAL_B), C114.2 (TERMINAL_B), C115.2 (TERMINAL_B), C116.2 (TERMINAL_B), C117.2 (TERMINAL_B), C118.2 (TERMINAL_B), C119.2 (TERMINAL_B); also elsewhere on the board
LED_5V: C11.1 (TERMINAL_A), C12.1 (TERMINAL_A); also elsewhere on the board

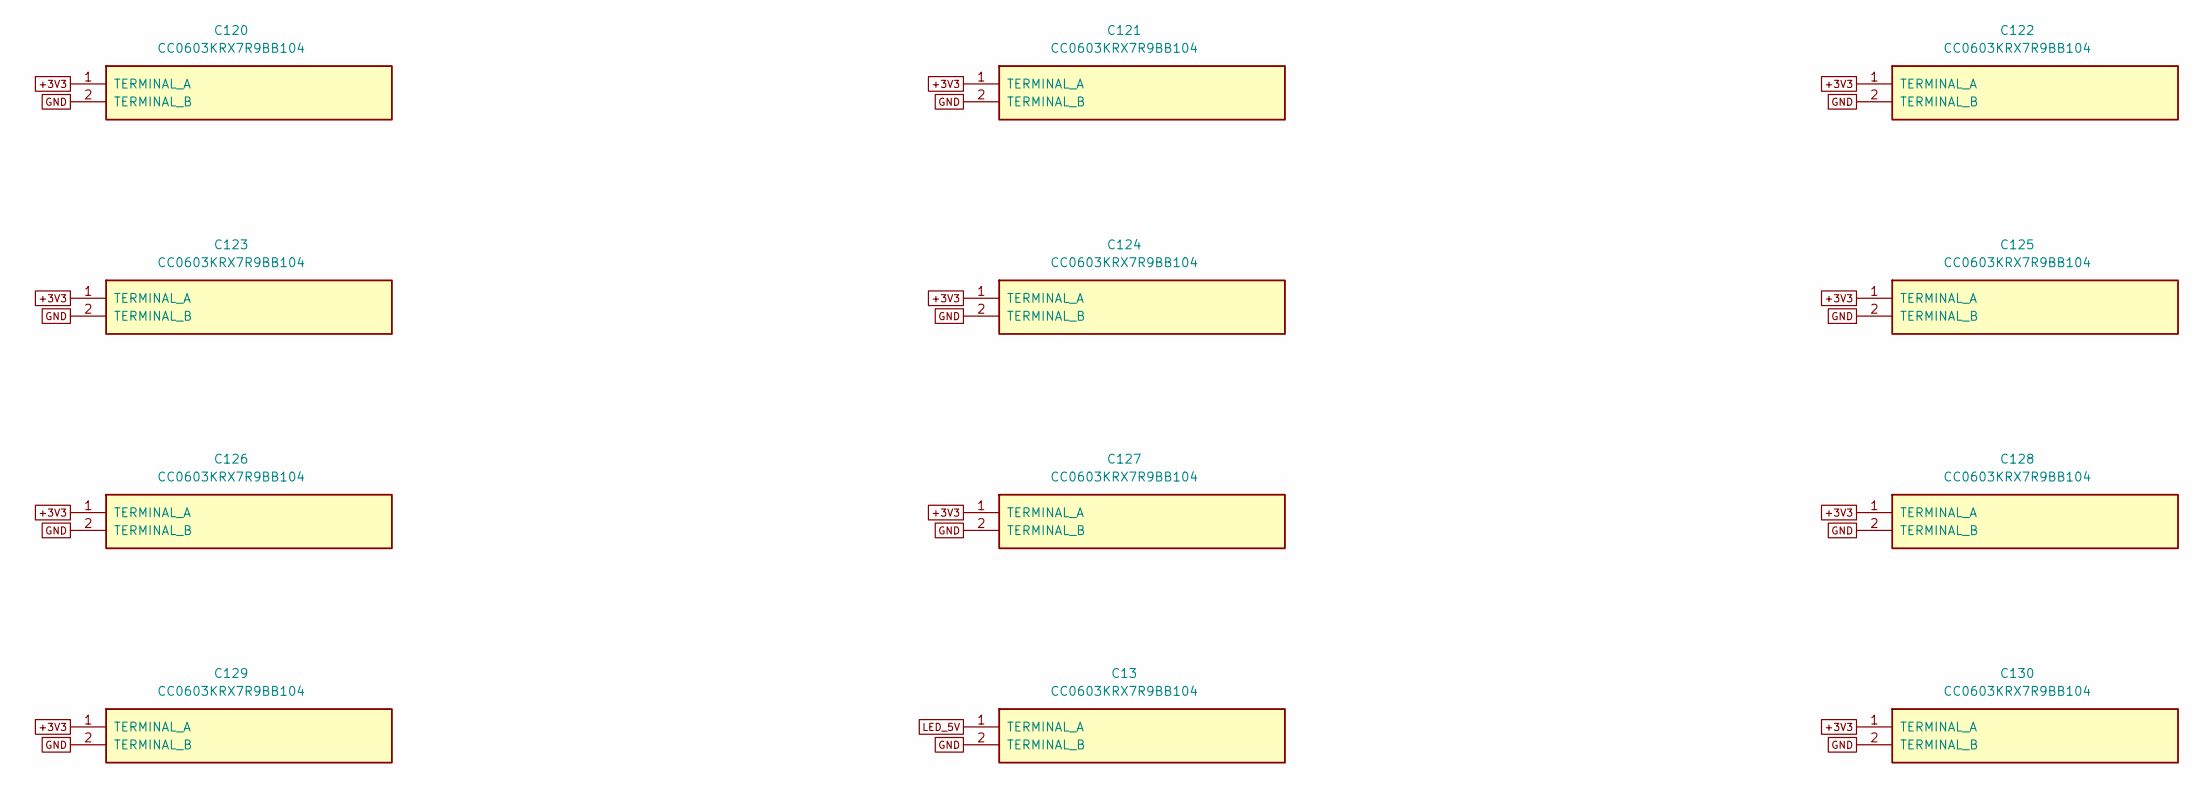
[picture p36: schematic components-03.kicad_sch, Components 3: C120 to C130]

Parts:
C13, C120, C121, C122, C123, C124, C125, C126, C127, C128, C129, C130: CC0603KRX7R9BB104; CAP_100N

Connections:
+3V3: C120.1 (TERMINAL_A), C121.1 (TERMINAL_A), C122.1 (TERMINAL_A), C123.1 (TERMINAL_A), C124.1 (TERMINAL_A), C125.1 (TERMINAL_A), C126.1 (TERMINAL_A), C127.1 (TERMINAL_A), C128.1 (TERMINAL_A), C129.1 (TERMINAL_A), C130.1 (TERMINAL_A); also elsewhere on the board
GND: C13.2 (TERMINAL_B), C120.2 (TERMINAL_B), C121.2 (TERMINAL_B), C122.2 (TERMINAL_B), C123.2 (TERMINAL_B), C124.2 (TERMINAL_B), C125.2 (TERMINAL_B), C126.2 (TERMINAL_B), C127.2 (TERMINAL_B), C128.2 (TERMINAL_B), C129.2 (TERMINAL_B), C130.2 (TERMINAL_B); also elsewhere on the board
LED_5V: C13.1 (TERMINAL_A); also elsewhere on the board

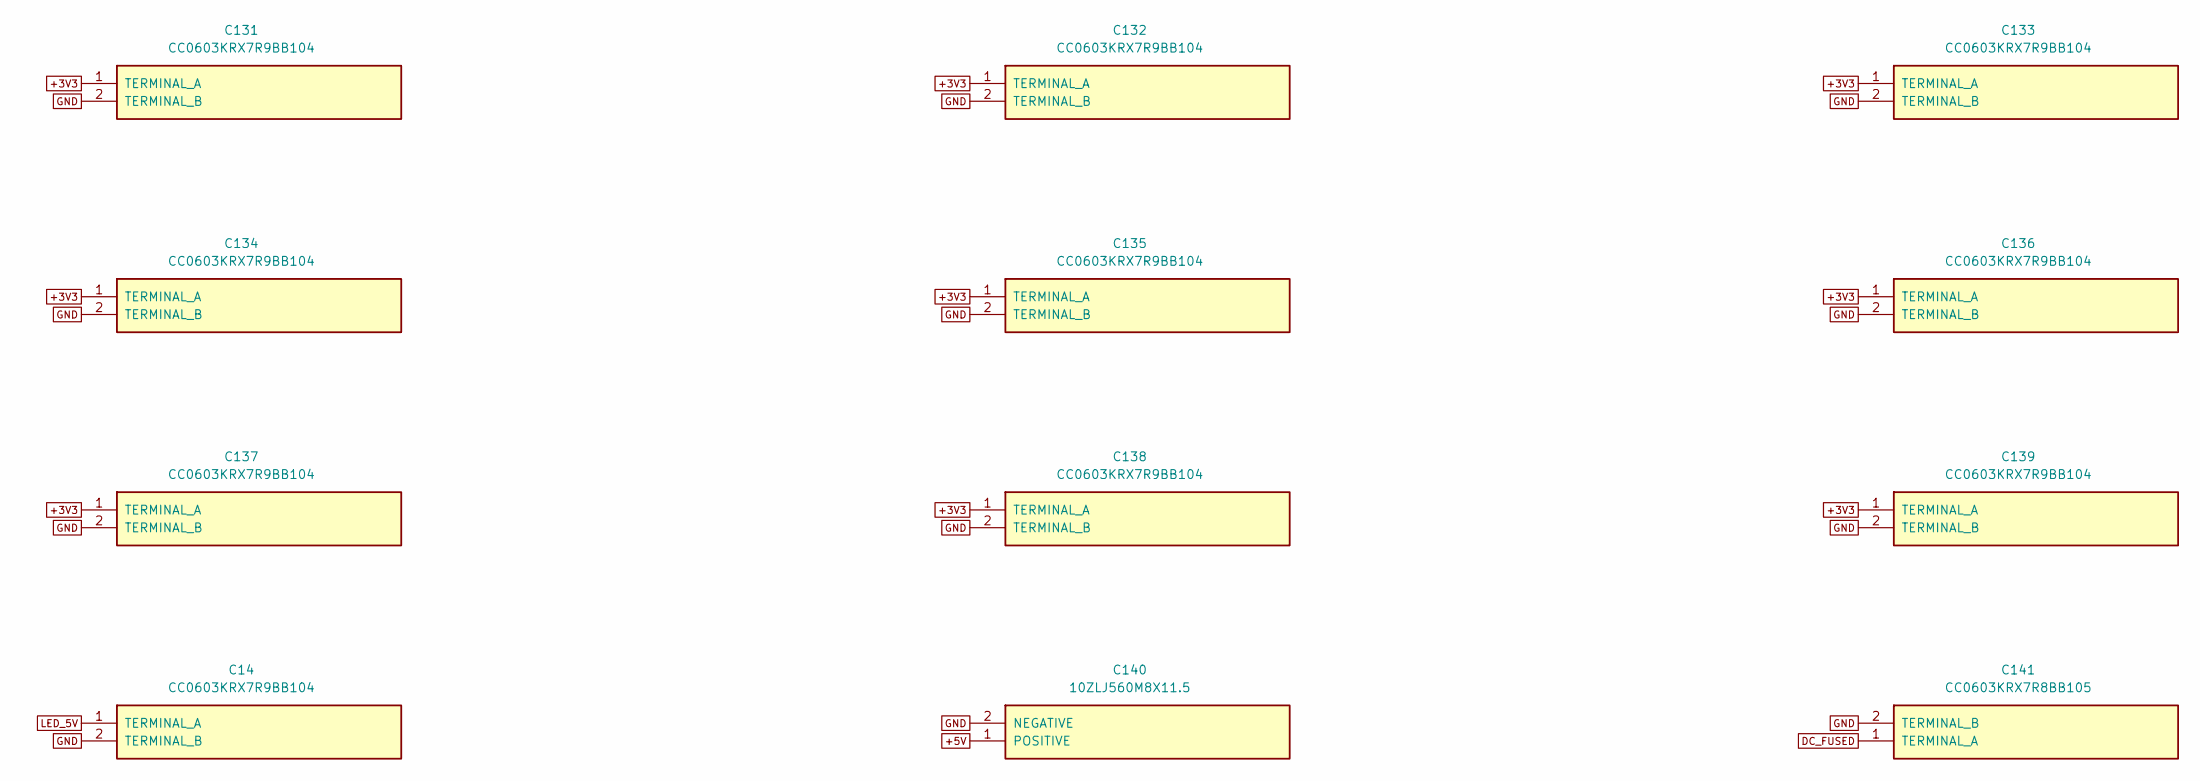
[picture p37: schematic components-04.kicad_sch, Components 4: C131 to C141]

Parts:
C14, C131, C132, C133, C134, C135, C136, C137, C138, C139: CC0603KRX7R9BB104; CAP_100N
C140: 10ZLJ560M8X11.5; CAP_560U
C141: CC0603KRX7R8BB105; CAP_1U

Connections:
+3V3: C131.1 (TERMINAL_A), C132.1 (TERMINAL_A), C133.1 (TERMINAL_A), C134.1 (TERMINAL_A), C135.1 (TERMINAL_A), C136.1 (TERMINAL_A), C137.1 (TERMINAL_A), C138.1 (TERMINAL_A), C139.1 (TERMINAL_A); also elsewhere on the board
+5V: C140.1 (POSITIVE); also elsewhere on the board
DC_FUSED: C141.1 (TERMINAL_A); also elsewhere on the board
GND: C14.2 (TERMINAL_B), C131.2 (TERMINAL_B), C132.2 (TERMINAL_B), C133.2 (TERMINAL_B), C134.2 (TERMINAL_B), C135.2 (TERMINAL_B), C136.2 (TERMINAL_B), C137.2 (TERMINAL_B), C138.2 (TERMINAL_B), C139.2 (TERMINAL_B), C140.2 (NEGATIVE), C141.2 (TERMINAL_B); also elsewhere on the board
LED_5V: C14.1 (TERMINAL_A); also elsewhere on the board

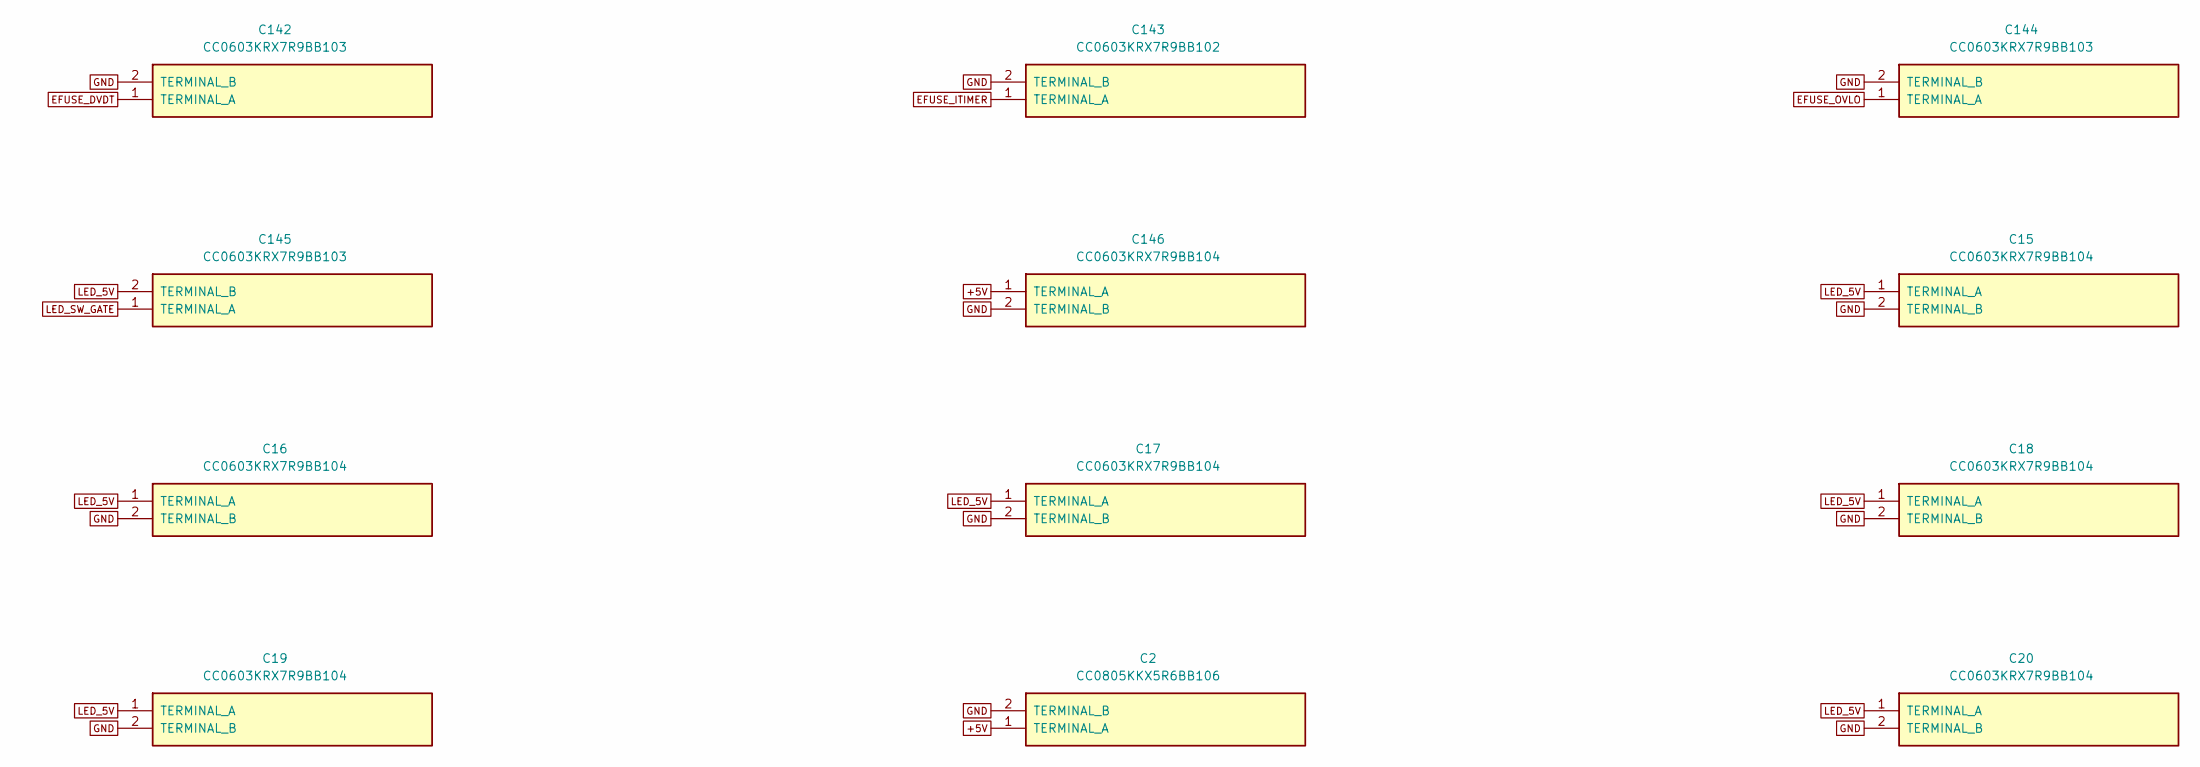
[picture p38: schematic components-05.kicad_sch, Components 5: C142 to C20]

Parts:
C2: CC0805KKX5R6BB106; CAP_10U
C15, C16, C17, C18, C19, C20, C146: CC0603KRX7R9BB104; CAP_100N
C142, C144, C145: CC0603KRX7R9BB103; CAP_10N
C143: CC0603KRX7R9BB102; CAP_1N

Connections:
+5V: C2.1 (TERMINAL_A), C146.1 (TERMINAL_A); also elsewhere on the board
EFUSE_DVDT: C142.1 (TERMINAL_A); also elsewhere on the board
EFUSE_ITIMER: C143.1 (TERMINAL_A); also elsewhere on the board
EFUSE_OVLO: C144.1 (TERMINAL_A); also elsewhere on the board
GND: C2.2 (TERMINAL_B), C15.2 (TERMINAL_B), C16.2 (TERMINAL_B), C17.2 (TERMINAL_B), C18.2 (TERMINAL_B), C19.2 (TERMINAL_B), C20.2 (TERMINAL_B), C142.2 (TERMINAL_B), C143.2 (TERMINAL_B), C144.2 (TERMINAL_B), C146.2 (TERMINAL_B); also elsewhere on the board
LED_5V: C15.1 (TERMINAL_A), C16.1 (TERMINAL_A), C17.1 (TERMINAL_A), C18.1 (TERMINAL_A), C19.1 (TERMINAL_A), C20.1 (TERMINAL_A), C145.2 (TERMINAL_B); also elsewhere on the board
LED_SW_GATE: C145.1 (TERMINAL_A); also elsewhere on the board

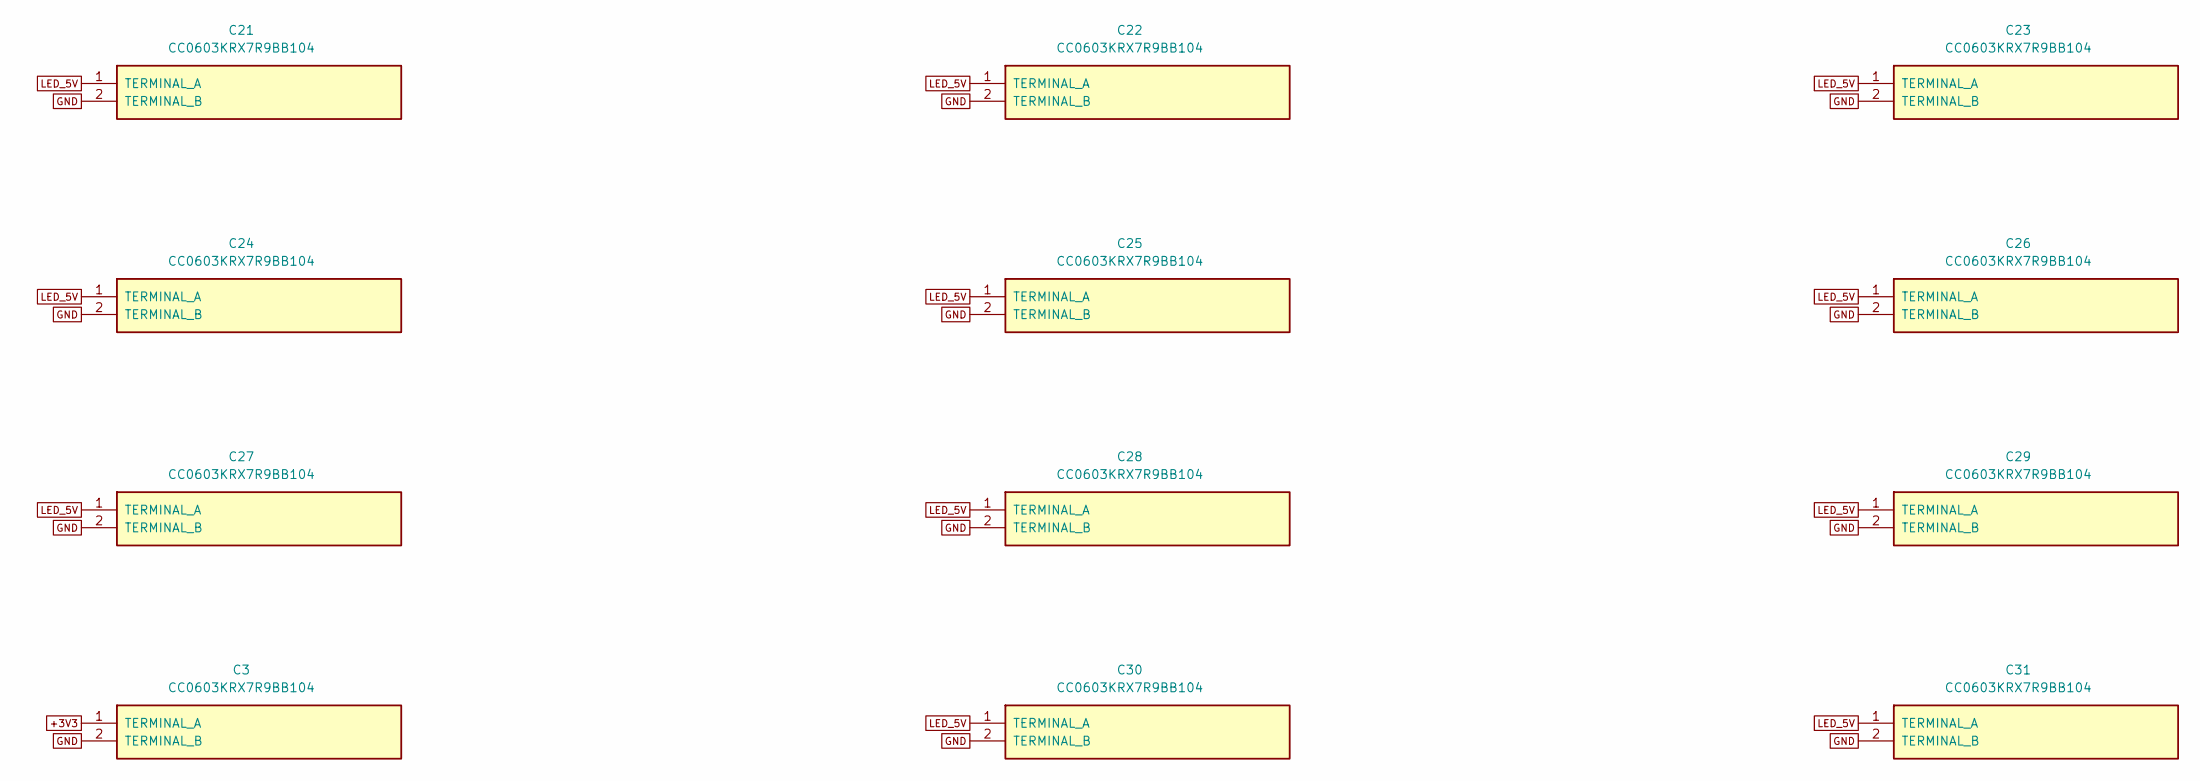
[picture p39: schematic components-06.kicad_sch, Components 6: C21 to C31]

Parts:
C3, C21, C22, C23, C24, C25, C26, C27, C28, C29, C30, C31: CC0603KRX7R9BB104; CAP_100N

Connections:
+3V3: C3.1 (TERMINAL_A); also elsewhere on the board
GND: C3.2 (TERMINAL_B), C21.2 (TERMINAL_B), C22.2 (TERMINAL_B), C23.2 (TERMINAL_B), C24.2 (TERMINAL_B), C25.2 (TERMINAL_B), C26.2 (TERMINAL_B), C27.2 (TERMINAL_B), C28.2 (TERMINAL_B), C29.2 (TERMINAL_B), C30.2 (TERMINAL_B), C31.2 (TERMINAL_B); also elsewhere on the board
LED_5V: C21.1 (TERMINAL_A), C22.1 (TERMINAL_A), C23.1 (TERMINAL_A), C24.1 (TERMINAL_A), C25.1 (TERMINAL_A), C26.1 (TERMINAL_A), C27.1 (TERMINAL_A), C28.1 (TERMINAL_A), C29.1 (TERMINAL_A), C30.1 (TERMINAL_A), C31.1 (TERMINAL_A); also elsewhere on the board

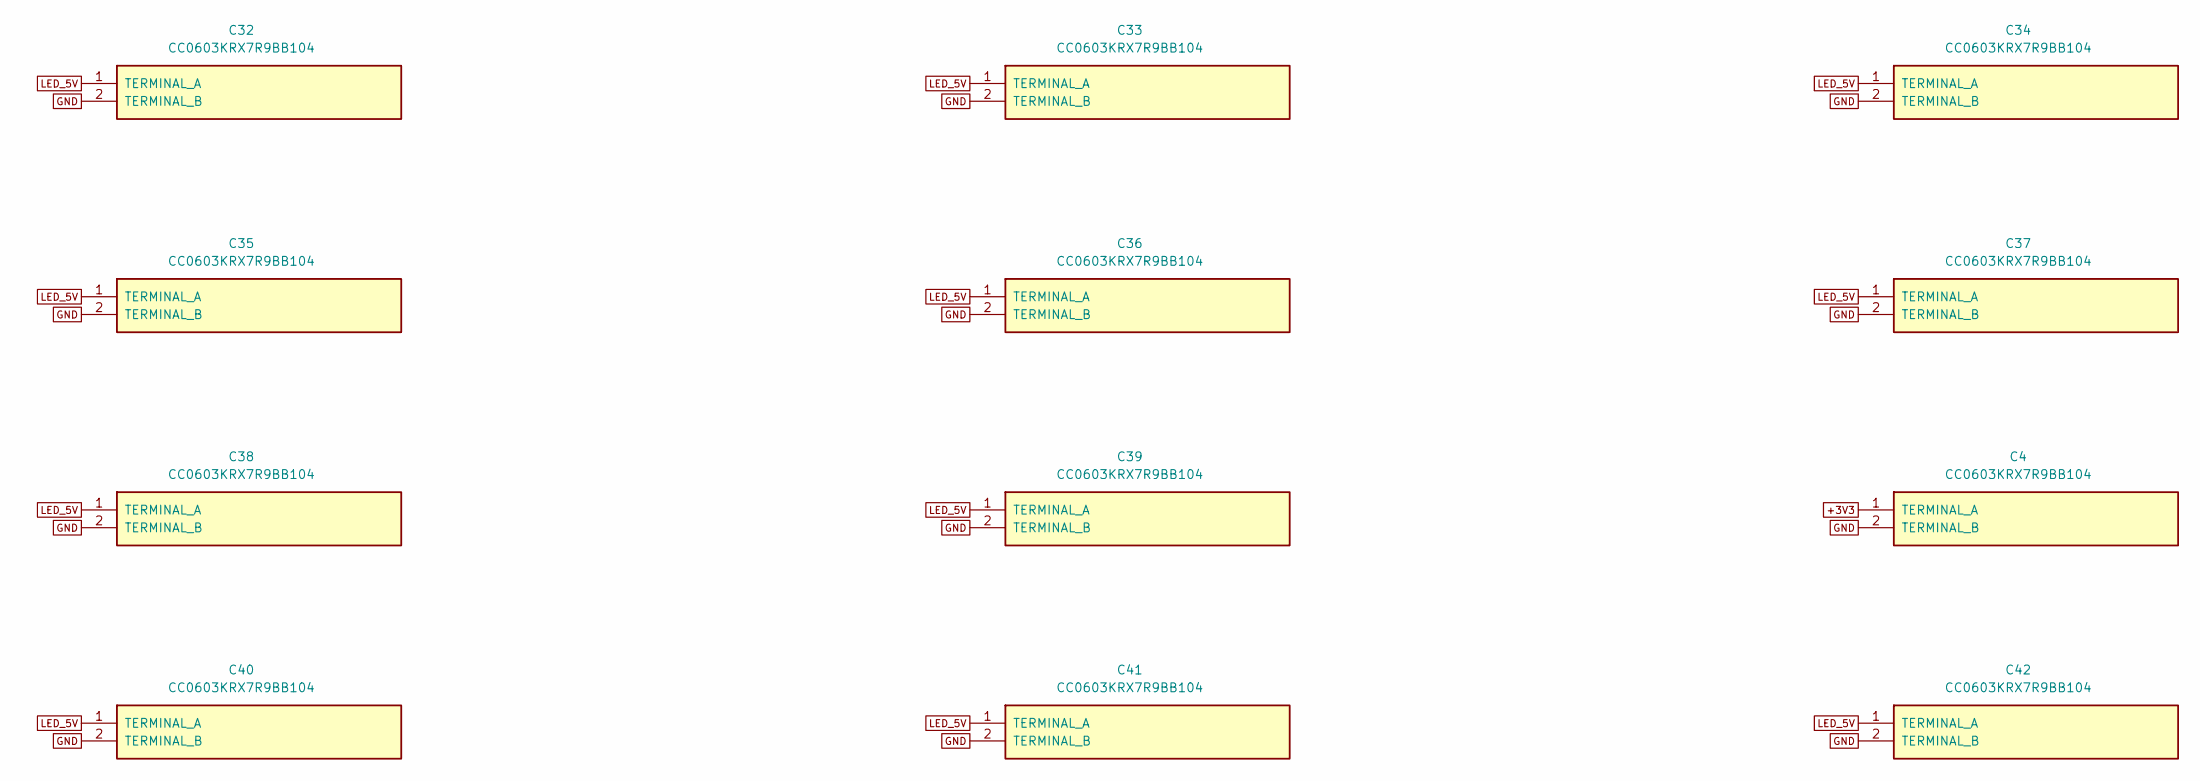
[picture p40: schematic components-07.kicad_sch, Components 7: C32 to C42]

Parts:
C4, C32, C33, C34, C35, C36, C37, C38, C39, C40, C41, C42: CC0603KRX7R9BB104; CAP_100N

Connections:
+3V3: C4.1 (TERMINAL_A); also elsewhere on the board
GND: C4.2 (TERMINAL_B), C32.2 (TERMINAL_B), C33.2 (TERMINAL_B), C34.2 (TERMINAL_B), C35.2 (TERMINAL_B), C36.2 (TERMINAL_B), C37.2 (TERMINAL_B), C38.2 (TERMINAL_B), C39.2 (TERMINAL_B), C40.2 (TERMINAL_B), C41.2 (TERMINAL_B), C42.2 (TERMINAL_B); also elsewhere on the board
LED_5V: C32.1 (TERMINAL_A), C33.1 (TERMINAL_A), C34.1 (TERMINAL_A), C35.1 (TERMINAL_A), C36.1 (TERMINAL_A), C37.1 (TERMINAL_A), C38.1 (TERMINAL_A), C39.1 (TERMINAL_A), C40.1 (TERMINAL_A), C41.1 (TERMINAL_A), C42.1 (TERMINAL_A); also elsewhere on the board

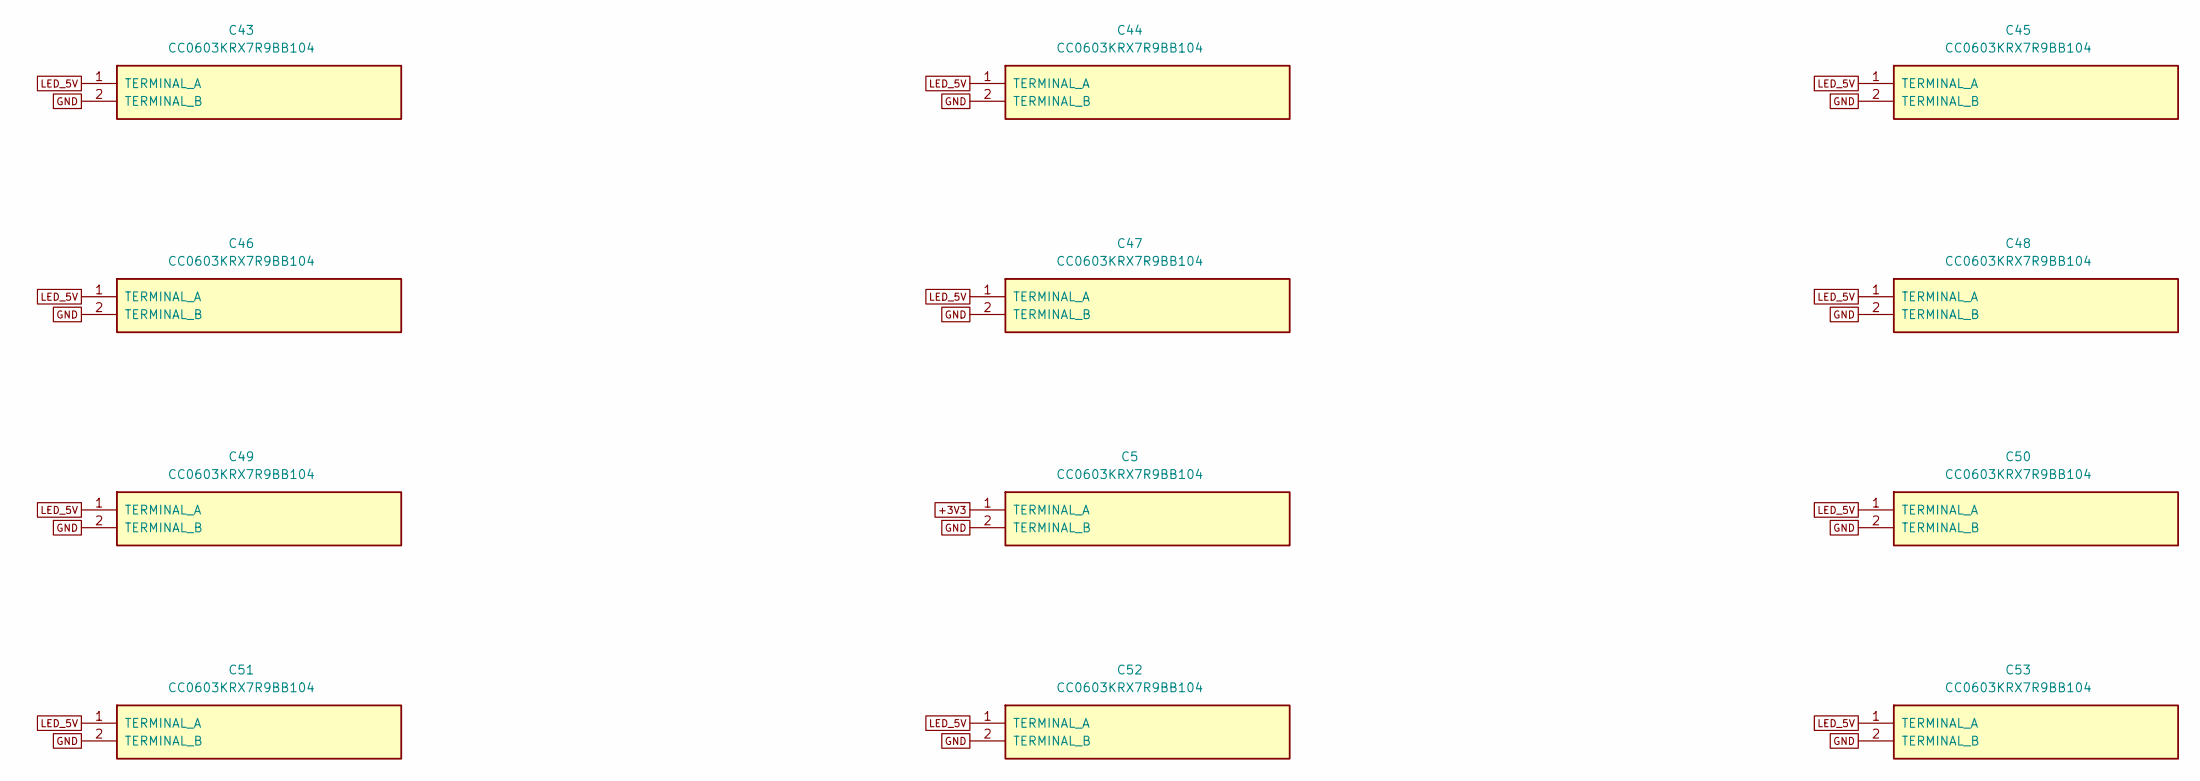
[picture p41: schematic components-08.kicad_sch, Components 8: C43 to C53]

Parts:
C5, C43, C44, C45, C46, C47, C48, C49, C50, C51, C52, C53: CC0603KRX7R9BB104; CAP_100N

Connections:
+3V3: C5.1 (TERMINAL_A); also elsewhere on the board
GND: C5.2 (TERMINAL_B), C43.2 (TERMINAL_B), C44.2 (TERMINAL_B), C45.2 (TERMINAL_B), C46.2 (TERMINAL_B), C47.2 (TERMINAL_B), C48.2 (TERMINAL_B), C49.2 (TERMINAL_B), C50.2 (TERMINAL_B), C51.2 (TERMINAL_B), C52.2 (TERMINAL_B), C53.2 (TERMINAL_B); also elsewhere on the board
LED_5V: C43.1 (TERMINAL_A), C44.1 (TERMINAL_A), C45.1 (TERMINAL_A), C46.1 (TERMINAL_A), C47.1 (TERMINAL_A), C48.1 (TERMINAL_A), C49.1 (TERMINAL_A), C50.1 (TERMINAL_A), C51.1 (TERMINAL_A), C52.1 (TERMINAL_A), C53.1 (TERMINAL_A); also elsewhere on the board

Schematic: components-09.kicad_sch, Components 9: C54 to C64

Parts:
C6, C54, C55, C56, C57, C58, C59, C60, C61, C62, C63, C64: CC0603KRX7R9BB104; CAP_100N

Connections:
+3V3: C6.1 (TERMINAL_A); also elsewhere on the board
GND: C6.2 (TERMINAL_B), C54.2 (TERMINAL_B), C55.2 (TERMINAL_B), C56.2 (TERMINAL_B), C57.2 (TERMINAL_B), C58.2 (TERMINAL_B), C59.2 (TERMINAL_B), C60.2 (TERMINAL_B), C61.2 (TERMINAL_B), C62.2 (TERMINAL_B), C63.2 (TERMINAL_B), C64.2 (TERMINAL_B); also elsewhere on the board
LED_5V: C54.1 (TERMINAL_A), C55.1 (TERMINAL_A), C56.1 (TERMINAL_A), C57.1 (TERMINAL_A), C58.1 (TERMINAL_A), C59.1 (TERMINAL_A), C60.1 (TERMINAL_A), C61.1 (TERMINAL_A), C62.1 (TERMINAL_A), C63.1 (TERMINAL_A), C64.1 (TERMINAL_A); also elsewhere on the board

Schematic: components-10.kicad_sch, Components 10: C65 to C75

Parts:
C7, C65, C66, C67, C68, C69, C70, C71, C72, C73, C74, C75: CC0603KRX7R9BB104; CAP_100N

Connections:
+3V3: C72.1 (TERMINAL_A), C73.1 (TERMINAL_A), C74.1 (TERMINAL_A), C75.1 (TERMINAL_A); also elsewhere on the board
+5V: C7.1 (TERMINAL_A); also elsewhere on the board
GND: C7.2 (TERMINAL_B), C65.2 (TERMINAL_B), C66.2 (TERMINAL_B), C67.2 (TERMINAL_B), C68.2 (TERMINAL_B), C69.2 (TERMINAL_B), C70.2 (TERMINAL_B), C71.2 (TERMINAL_B), C72.2 (TERMINAL_B), C73.2 (TERMINAL_B), C74.2 (TERMINAL_B), C75.2 (TERMINAL_B); also elsewhere on the board
LED_5V: C65.1 (TERMINAL_A), C66.1 (TERMINAL_A), C67.1 (TERMINAL_A), C68.1 (TERMINAL_A), C69.1 (TERMINAL_A), C70.1 (TERMINAL_A), C71.1 (TERMINAL_A); also elsewhere on the board

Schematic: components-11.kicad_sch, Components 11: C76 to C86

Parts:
C8, C76, C77, C78, C79, C80, C81, C82, C83, C84, C85, C86: CC0603KRX7R9BB104; CAP_100N

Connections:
+3V3: C76.1 (TERMINAL_A), C77.1 (TERMINAL_A), C78.1 (TERMINAL_A), C79.1 (TERMINAL_A), C80.1 (TERMINAL_A), C81.1 (TERMINAL_A), C82.1 (TERMINAL_A), C83.1 (TERMINAL_A), C84.1 (TERMINAL_A), C85.1 (TERMINAL_A), C86.1 (TERMINAL_A); also elsewhere on the board
GND: C8.2 (TERMINAL_B), C76.2 (TERMINAL_B), C77.2 (TERMINAL_B), C78.2 (TERMINAL_B), C79.2 (TERMINAL_B), C80.2 (TERMINAL_B), C81.2 (TERMINAL_B), C82.2 (TERMINAL_B), C83.2 (TERMINAL_B), C84.2 (TERMINAL_B), C85.2 (TERMINAL_B), C86.2 (TERMINAL_B); also elsewhere on the board
LED_5V: C8.1 (TERMINAL_A); also elsewhere on the board

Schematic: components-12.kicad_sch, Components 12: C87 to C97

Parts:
C9, C87, C88, C89, C90, C91, C92, C93, C94, C95, C96, C97: CC0603KRX7R9BB104; CAP_100N

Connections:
+3V3: C87.1 (TERMINAL_A), C88.1 (TERMINAL_A), C89.1 (TERMINAL_A), C90.1 (TERMINAL_A), C91.1 (TERMINAL_A), C92.1 (TERMINAL_A), C93.1 (TERMINAL_A), C94.1 (TERMINAL_A), C95.1 (TERMINAL_A), C96.1 (TERMINAL_A), C97.1 (TERMINAL_A); also elsewhere on the board
GND: C9.2 (TERMINAL_B), C87.2 (TERMINAL_B), C88.2 (TERMINAL_B), C89.2 (TERMINAL_B), C90.2 (TERMINAL_B), C91.2 (TERMINAL_B), C92.2 (TERMINAL_B), C93.2 (TERMINAL_B), C94.2 (TERMINAL_B), C95.2 (TERMINAL_B), C96.2 (TERMINAL_B), C97.2 (TERMINAL_B); also elsewhere on the board
LED_5V: C9.1 (TERMINAL_A); also elsewhere on the board

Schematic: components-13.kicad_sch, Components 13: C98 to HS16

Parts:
C98, C99: CC0603KRX7R9BB104; CAP_100N
D1: SMBJ12CA; TVS_12V0
F1: 0453002.MR; FUSE_2A
HS1, HS10, HS11, HS12, HS13, HS14, HS15, HS16: DRV5032FCDBZR; HALL_SENSOR

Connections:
+3V3: C98.1 (TERMINAL_A), C99.1 (TERMINAL_A), HS1.1 (SUPPLY), HS10.1 (SUPPLY), HS11.1 (SUPPLY), HS12.1 (SUPPLY), HS13.1 (SUPPLY), HS14.1 (SUPPLY), HS15.1 (SUPPLY), HS16.1 (SUPPLY); also elsewhere on the board
DC_FUSED: D1.1 (PROTECTED_INPUT), F1.2 (FUSED_OUTPUT); also elsewhere on the board
DC_IN: F1.1 (UNFUSED_INPUT); also elsewhere on the board
GND: C98.2 (TERMINAL_B), C99.2 (TERMINAL_B), D1.2 (GROUND), HS1.3 (GROUND), HS10.3 (GROUND), HS11.3 (GROUND), HS12.3 (GROUND), HS13.3 (GROUND), HS14.3 (GROUND), HS15.3 (GROUND), HS16.3 (GROUND); also elsewhere on the board
SQ_A1: HS1.2 (ACTIVE_LOW_OUTPUT); also elsewhere on the board
SQ_A4: HS13.2 (ACTIVE_LOW_OUTPUT); also elsewhere on the board
SQ_B3: HS10.2 (ACTIVE_LOW_OUTPUT); also elsewhere on the board
SQ_B4: HS14.2 (ACTIVE_LOW_OUTPUT); also elsewhere on the board
SQ_C3: HS11.2 (ACTIVE_LOW_OUTPUT); also elsewhere on the board
SQ_C4: HS15.2 (ACTIVE_LOW_OUTPUT); also elsewhere on the board
SQ_D3: HS12.2 (ACTIVE_LOW_OUTPUT); also elsewhere on the board
SQ_D4: HS16.2 (ACTIVE_LOW_OUTPUT); also elsewhere on the board

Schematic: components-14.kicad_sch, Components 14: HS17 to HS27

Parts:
HS2, HS17, HS18, HS19, HS20, HS21, HS22, HS23, HS24, HS25, HS26, HS27: DRV5032FCDBZR; HALL_SENSOR

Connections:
+3V3: HS2.1 (SUPPLY), HS17.1 (SUPPLY), HS18.1 (SUPPLY), HS19.1 (SUPPLY), HS20.1 (SUPPLY), HS21.1 (SUPPLY), HS22.1 (SUPPLY), HS23.1 (SUPPLY), HS24.1 (SUPPLY), HS25.1 (SUPPLY), HS26.1 (SUPPLY), HS27.1 (SUPPLY); also elsewhere on the board
GND: HS2.3 (GROUND), HS17.3 (GROUND), HS18.3 (GROUND), HS19.3 (GROUND), HS20.3 (GROUND), HS21.3 (GROUND), HS22.3 (GROUND), HS23.3 (GROUND), HS24.3 (GROUND), HS25.3 (GROUND), HS26.3 (GROUND), HS27.3 (GROUND); also elsewhere on the board
SQ_B1: HS2.2 (ACTIVE_LOW_OUTPUT); also elsewhere on the board
SQ_E1: HS17.2 (ACTIVE_LOW_OUTPUT); also elsewhere on the board
SQ_E2: HS21.2 (ACTIVE_LOW_OUTPUT); also elsewhere on the board
SQ_E3: HS25.2 (ACTIVE_LOW_OUTPUT); also elsewhere on the board
SQ_F1: HS18.2 (ACTIVE_LOW_OUTPUT); also elsewhere on the board
SQ_F2: HS22.2 (ACTIVE_LOW_OUTPUT); also elsewhere on the board
SQ_F3: HS26.2 (ACTIVE_LOW_OUTPUT); also elsewhere on the board
SQ_G1: HS19.2 (ACTIVE_LOW_OUTPUT); also elsewhere on the board
SQ_G2: HS23.2 (ACTIVE_LOW_OUTPUT); also elsewhere on the board
SQ_G3: HS27.2 (ACTIVE_LOW_OUTPUT); also elsewhere on the board
SQ_H1: HS20.2 (ACTIVE_LOW_OUTPUT); also elsewhere on the board
SQ_H2: HS24.2 (ACTIVE_LOW_OUTPUT); also elsewhere on the board

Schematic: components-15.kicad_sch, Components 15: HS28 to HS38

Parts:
HS3, HS28, HS29, HS30, HS31, HS32, HS33, HS34, HS35, HS36, HS37, HS38: DRV5032FCDBZR; HALL_SENSOR

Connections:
+3V3: HS3.1 (SUPPLY), HS28.1 (SUPPLY), HS29.1 (SUPPLY), HS30.1 (SUPPLY), HS31.1 (SUPPLY), HS32.1 (SUPPLY), HS33.1 (SUPPLY), HS34.1 (SUPPLY), HS35.1 (SUPPLY), HS36.1 (SUPPLY), HS37.1 (SUPPLY), HS38.1 (SUPPLY); also elsewhere on the board
GND: HS3.3 (GROUND), HS28.3 (GROUND), HS29.3 (GROUND), HS30.3 (GROUND), HS31.3 (GROUND), HS32.3 (GROUND), HS33.3 (GROUND), HS34.3 (GROUND), HS35.3 (GROUND), HS36.3 (GROUND), HS37.3 (GROUND), HS38.3 (GROUND); also elsewhere on the board
SQ_A5: HS33.2 (ACTIVE_LOW_OUTPUT); also elsewhere on the board
SQ_A6: HS37.2 (ACTIVE_LOW_OUTPUT); also elsewhere on the board
SQ_B5: HS34.2 (ACTIVE_LOW_OUTPUT); also elsewhere on the board
SQ_B6: HS38.2 (ACTIVE_LOW_OUTPUT); also elsewhere on the board
SQ_C1: HS3.2 (ACTIVE_LOW_OUTPUT); also elsewhere on the board
SQ_C5: HS35.2 (ACTIVE_LOW_OUTPUT); also elsewhere on the board
SQ_D5: HS36.2 (ACTIVE_LOW_OUTPUT); also elsewhere on the board
SQ_E4: HS29.2 (ACTIVE_LOW_OUTPUT); also elsewhere on the board
SQ_F4: HS30.2 (ACTIVE_LOW_OUTPUT); also elsewhere on the board
SQ_G4: HS31.2 (ACTIVE_LOW_OUTPUT); also elsewhere on the board
SQ_H3: HS28.2 (ACTIVE_LOW_OUTPUT); also elsewhere on the board
SQ_H4: HS32.2 (ACTIVE_LOW_OUTPUT); also elsewhere on the board

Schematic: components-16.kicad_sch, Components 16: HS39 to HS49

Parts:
HS4, HS39, HS40, HS41, HS42, HS43, HS44, HS45, HS46, HS47, HS48, HS49: DRV5032FCDBZR; HALL_SENSOR

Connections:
+3V3: HS4.1 (SUPPLY), HS39.1 (SUPPLY), HS40.1 (SUPPLY), HS41.1 (SUPPLY), HS42.1 (SUPPLY), HS43.1 (SUPPLY), HS44.1 (SUPPLY), HS45.1 (SUPPLY), HS46.1 (SUPPLY), HS47.1 (SUPPLY), HS48.1 (SUPPLY), HS49.1 (SUPPLY); also elsewhere on the board
GND: HS4.3 (GROUND), HS39.3 (GROUND), HS40.3 (GROUND), HS41.3 (GROUND), HS42.3 (GROUND), HS43.3 (GROUND), HS44.3 (GROUND), HS45.3 (GROUND), HS46.3 (GROUND), HS47.3 (GROUND), HS48.3 (GROUND), HS49.3 (GROUND); also elsewhere on the board
SQ_A7: HS41.2 (ACTIVE_LOW_OUTPUT); also elsewhere on the board
SQ_A8: HS45.2 (ACTIVE_LOW_OUTPUT); also elsewhere on the board
SQ_B7: HS42.2 (ACTIVE_LOW_OUTPUT); also elsewhere on the board
SQ_B8: HS46.2 (ACTIVE_LOW_OUTPUT); also elsewhere on the board
SQ_C6: HS39.2 (ACTIVE_LOW_OUTPUT); also elsewhere on the board
SQ_C7: HS43.2 (ACTIVE_LOW_OUTPUT); also elsewhere on the board
SQ_C8: HS47.2 (ACTIVE_LOW_OUTPUT); also elsewhere on the board
SQ_D1: HS4.2 (ACTIVE_LOW_OUTPUT); also elsewhere on the board
SQ_D6: HS40.2 (ACTIVE_LOW_OUTPUT); also elsewhere on the board
SQ_D7: HS44.2 (ACTIVE_LOW_OUTPUT); also elsewhere on the board
SQ_D8: HS48.2 (ACTIVE_LOW_OUTPUT); also elsewhere on the board
SQ_E5: HS49.2 (ACTIVE_LOW_OUTPUT); also elsewhere on the board

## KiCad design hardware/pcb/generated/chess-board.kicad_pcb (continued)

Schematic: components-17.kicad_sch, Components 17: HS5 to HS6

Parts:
HS5, HS6, HS50, HS51, HS52, HS53, HS54, HS55, HS56, HS57, HS58, HS59: DRV5032FCDBZR; HALL_SENSOR

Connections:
+3V3: HS5.1 (SUPPLY), HS6.1 (SUPPLY), HS50.1 (SUPPLY), HS51.1 (SUPPLY), HS52.1 (SUPPLY), HS53.1 (SUPPLY), HS54.1 (SUPPLY), HS55.1 (SUPPLY), HS56.1 (SUPPLY), HS57.1 (SUPPLY), HS58.1 (SUPPLY), HS59.1 (SUPPLY); also elsewhere on the board
GND: HS5.3 (GROUND), HS6.3 (GROUND), HS50.3 (GROUND), HS51.3 (GROUND), HS52.3 (GROUND), HS53.3 (GROUND), HS54.3 (GROUND), HS55.3 (GROUND), HS56.3 (GROUND), HS57.3 (GROUND), HS58.3 (GROUND), HS59.3 (GROUND); also elsewhere on the board
SQ_A2: HS5.2 (ACTIVE_LOW_OUTPUT); also elsewhere on the board
SQ_B2: HS6.2 (ACTIVE_LOW_OUTPUT); also elsewhere on the board
SQ_E6: HS53.2 (ACTIVE_LOW_OUTPUT); also elsewhere on the board
SQ_E7: HS57.2 (ACTIVE_LOW_OUTPUT); also elsewhere on the board
SQ_F5: HS50.2 (ACTIVE_LOW_OUTPUT); also elsewhere on the board
SQ_F6: HS54.2 (ACTIVE_LOW_OUTPUT); also elsewhere on the board
SQ_F7: HS58.2 (ACTIVE_LOW_OUTPUT); also elsewhere on the board
SQ_G5: HS51.2 (ACTIVE_LOW_OUTPUT); also elsewhere on the board
SQ_G6: HS55.2 (ACTIVE_LOW_OUTPUT); also elsewhere on the board
SQ_G7: HS59.2 (ACTIVE_LOW_OUTPUT); also elsewhere on the board
SQ_H5: HS52.2 (ACTIVE_LOW_OUTPUT); also elsewhere on the board
SQ_H6: HS56.2 (ACTIVE_LOW_OUTPUT); also elsewhere on the board

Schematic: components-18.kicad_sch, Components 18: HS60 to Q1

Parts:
HS7, HS8, HS9, HS60, HS61, HS62, HS63, HS64: DRV5032FCDBZR; HALL_SENSOR
J1: PPPC202LFBN-RC; PI_ZERO_HEADER
J2: SM04B-SRSS-TB; OLED_HEADER
J4: B4PS-VH; POWER_HEADER
Q1: Si4403DDY-T1-GE3; LED_SWITCH

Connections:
+3V3: HS7.1 (SUPPLY), HS8.1 (SUPPLY), HS9.1 (SUPPLY), HS60.1 (SUPPLY), HS61.1 (SUPPLY), HS62.1 (SUPPLY), HS63.1 (SUPPLY), HS64.1 (SUPPLY), J1.1 (THREE_VOLTS_THREE), J1.17 (THREE_VOLTS_THREE_ALT), J2.2 (THREE_VOLTS_THREE); also elsewhere on the board
+5V: J1.2 (FIVE_VOLTS), J1.4 (FIVE_VOLTS_ALT), Q1.1 (SOURCE_1), Q1.2 (SOURCE_2), Q1.3 (SOURCE_3); also elsewhere on the board
BTN_DOWN: J1.31 (BUTTON_DOWN_GPIO6); also elsewhere on the board
BTN_F1: J1.38 (BUTTON_F1_GPIO20); also elsewhere on the board
BTN_F2: J1.40 (BUTTON_F2_GPIO21); also elsewhere on the board
BTN_F3: J1.15 (BUTTON_F3_GPIO22); also elsewhere on the board
BTN_F4: J1.16 (BUTTON_F4_GPIO23); also elsewhere on the board
BTN_F5: J1.18 (BUTTON_F5_GPIO24); also elsewhere on the board
BTN_LEFT: J1.32 (BUTTON_LEFT_GPIO12); also elsewhere on the board
BTN_OK: J1.36 (BUTTON_OK_GPIO16); also elsewhere on the board
BTN_PASS: J1.35 (BUTTON_PASS_GPIO19); also elsewhere on the board
BTN_RESET: J1.11 (BUTTON_RESET_GPIO17); also elsewhere on the board
BTN_RIGHT: J1.33 (BUTTON_RIGHT_GPIO13); also elsewhere on the board
BTN_UP: J1.29 (BUTTON_UP_GPIO5); also elsewhere on the board
DC_FUSED: J4.3 (FUSED_TO_SWITCH); also elsewhere on the board
DC_IN: J4.1 (DC_INPUT); also elsewhere on the board
GND: HS7.3 (GROUND), HS8.3 (GROUND), HS9.3 (GROUND), HS60.3 (GROUND), HS61.3 (GROUND), HS62.3 (GROUND), HS63.3 (GROUND), HS64.3 (GROUND), J1.6 (GROUND_6), J1.9 (GROUND_9), J1.14 (GROUND_14), J1.20 (GROUND_20), J1.25 (GROUND_25), J1.30 (GROUND_30), J1.34 (GROUND_34), J1.39 (GROUND_39), J2.1 (GROUND), J2.5 (MOUNTING_TAB_A), J2.6 (MOUNTING_TAB_B), J4.2 (GROUND); also elsewhere on the board
I2C_SCL: J1.5 (I2C_SCL), J2.3 (I2C_CLOCK); also elsewhere on the board
I2C_SDA: J1.3 (I2C_SDA), J2.4 (I2C_DATA); also elsewhere on the board
LED_5V: Q1.5 (DRAIN_5), Q1.6 (DRAIN_6), Q1.7 (DRAIN_7), Q1.8 (DRAIN_8); also elsewhere on the board
LED_EN: J1.37 (LED_EN_GPIO26); also elsewhere on the board
LED_SW_GATE: Q1.4 (GATE); also elsewhere on the board
RUN: J4.4 (RUN); also elsewhere on the board
SPI_CLK_3V3: J1.23 (SPI_CLOCK_GPIO11); also elsewhere on the board
SPI_DATA_3V3: J1.19 (SPI_DATA_GPIO10); also elsewhere on the board
SQ_A3: HS9.2 (ACTIVE_LOW_OUTPUT); also elsewhere on the board
SQ_C2: HS7.2 (ACTIVE_LOW_OUTPUT); also elsewhere on the board
SQ_D2: HS8.2 (ACTIVE_LOW_OUTPUT); also elsewhere on the board
SQ_E8: HS61.2 (ACTIVE_LOW_OUTPUT); also elsewhere on the board
SQ_F8: HS62.2 (ACTIVE_LOW_OUTPUT); also elsewhere on the board
SQ_G8: HS63.2 (ACTIVE_LOW_OUTPUT); also elsewhere on the board
SQ_H7: HS60.2 (ACTIVE_LOW_OUTPUT); also elsewhere on the board
SQ_H8: HS64.2 (ACTIVE_LOW_OUTPUT); also elsewhere on the board

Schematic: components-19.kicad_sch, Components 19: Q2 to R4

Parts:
Q2: BSS138LT1G; LED_SWITCH_DRIVER
R3: RC0603FR-071K65L; RES_1K65
R4: RT0603BRD07604KL; RES_604K_PRECISION
R10, R11, R12: RC0603FR-0756RL; RES_56
R13: RC0603FR-071KL; RES_1K
R14, R16: RC0603FR-07100KL; RES_100K
R15, R17, R18: RC0603FR-0710KL; RES_10K

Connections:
+5V: R15.2 (TERMINAL_B); also elsewhere on the board
DC_FUSED: R4.2 (TERMINAL_B); also elsewhere on the board
EFUSE_ILM: R3.1 (TERMINAL_A); also elsewhere on the board
EFUSE_OVLO: R4.1 (TERMINAL_A); also elsewhere on the board
GND: Q2.2 (SOURCE), R3.2 (TERMINAL_B), R14.2 (TERMINAL_B), R17.2 (TERMINAL_B), R18.2 (TERMINAL_B); also elsewhere on the board
LED_CLK_5V: R18.1 (TERMINAL_A); also elsewhere on the board
LED_DATA_5V: R17.1 (TERMINAL_A); also elsewhere on the board
LED_DATA_A2_TO_A3: R10.1 (TERMINAL_A); also elsewhere on the board
LED_DATA_A2_TO_A3_SRC: R10.2 (TERMINAL_B); also elsewhere on the board
LED_DATA_A4_TO_A5: R11.1 (TERMINAL_A); also elsewhere on the board
LED_DATA_A4_TO_A5_SRC: R11.2 (TERMINAL_B); also elsewhere on the board
LED_DATA_A6_TO_A7: R12.1 (TERMINAL_A); also elsewhere on the board
LED_DATA_A6_TO_A7_SRC: R12.2 (TERMINAL_B); also elsewhere on the board
LED_EN: R13.1 (TERMINAL_A); also elsewhere on the board
LED_EN_GATE: Q2.1 (GATE), R13.2 (TERMINAL_B), R14.1 (TERMINAL_A)
LED_EN_N: Q2.3 (DRAIN), R15.1 (TERMINAL_A), R16.1 (TERMINAL_A); also elsewhere on the board
LED_SW_GATE: R16.2 (TERMINAL_B); also elsewhere on the board

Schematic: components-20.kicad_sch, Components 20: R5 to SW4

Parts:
R5: RT0603BRD07169KL; RES_169K_PRECISION
R6: RT0603BRD07604KL; RES_604K_PRECISION
R7: RC0603FR-07261KL; RES_261K
R8: RC0603FR-071KL; RES_1K
R9: RC0603FR-0756RL; RES_56
SW1, SW2, SW3, SW4, SW10, SW11, SW12: TL1105CF100Q; BUTTON

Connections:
BTN_DOWN: SW2.1 (SIGNAL), SW2.1b (SIGNAL); also elsewhere on the board
BTN_F3: SW10.1 (SIGNAL), SW10.1b (SIGNAL); also elsewhere on the board
BTN_F4: SW11.1 (SIGNAL), SW11.1b (SIGNAL); also elsewhere on the board
BTN_F5: SW12.1 (SIGNAL), SW12.1b (SIGNAL); also elsewhere on the board
BTN_LEFT: SW3.1 (SIGNAL), SW3.1b (SIGNAL); also elsewhere on the board
BTN_RIGHT: SW4.1 (SIGNAL), SW4.1b (SIGNAL); also elsewhere on the board
BTN_UP: SW1.1 (SIGNAL), SW1.1b (SIGNAL); also elsewhere on the board
EFUSE_EN: R6.2 (TERMINAL_B), R7.1 (TERMINAL_A); also elsewhere on the board
EFUSE_OVLO: R5.1 (TERMINAL_A); also elsewhere on the board
GND: R5.2 (TERMINAL_B), R7.2 (TERMINAL_B), R8.2 (TERMINAL_B), SW1.2 (GROUND), SW1.2b (GROUND), SW2.2 (GROUND), SW2.2b (GROUND), SW3.2 (GROUND), SW3.2b (GROUND), SW4.2 (GROUND), SW4.2b (GROUND), SW10.2 (GROUND), SW10.2b (GROUND), SW11.2 (GROUND), SW11.2b (GROUND), SW12.2 (GROUND), SW12.2b (GROUND); also elsewhere on the board
LED_DATA_5V: R9.1 (TERMINAL_A); also elsewhere on the board
LED_DATA_BUF: R9.2 (TERMINAL_B); also elsewhere on the board
RUN: R6.1 (TERMINAL_A), R8.1 (TERMINAL_A); also elsewhere on the board

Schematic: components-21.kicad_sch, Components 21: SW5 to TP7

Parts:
SW5, SW6, SW7, SW8, SW9: TL1105CF100Q; BUTTON
TP1, TP2, TP3, TP4, TP5, TP6, TP7: S1751-46R; TEST_POINT

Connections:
+3V3: TP5.1; also elsewhere on the board
+5V: TP1.1; also elsewhere on the board
BTN_F1: SW8.1 (SIGNAL), SW8.1b (SIGNAL); also elsewhere on the board
BTN_F2: SW9.1 (SIGNAL), SW9.1b (SIGNAL); also elsewhere on the board
BTN_OK: SW5.1 (SIGNAL), SW5.1b (SIGNAL); also elsewhere on the board
BTN_PASS: SW7.1 (SIGNAL), SW7.1b (SIGNAL); also elsewhere on the board
BTN_RESET: SW6.1 (SIGNAL), SW6.1b (SIGNAL); also elsewhere on the board
GND: SW5.2 (GROUND), SW5.2b (GROUND), SW6.2 (GROUND), SW6.2b (GROUND), SW7.2 (GROUND), SW7.2b (GROUND), SW8.2 (GROUND), SW8.2b (GROUND), SW9.2 (GROUND), SW9.2b (GROUND), TP2.1; also elsewhere on the board
I2C_SCL: TP6.1; also elsewhere on the board
I2C_SDA: TP7.1; also elsewhere on the board
LED_CLK_5V: TP4.1; also elsewhere on the board
LED_DATA_5V: TP3.1; also elsewhere on the board

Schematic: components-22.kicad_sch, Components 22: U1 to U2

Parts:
U1, U2: TCA9554DWR; TCA9554
U10, U11, U12, U13, U14, U15, U16, U17, U18, U19: SK9822-A; SK9822

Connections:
+3V3: U1.16 (SUPPLY), U2.1 (ADDRESS_0), U2.16 (SUPPLY); also elsewhere on the board
GND: U1.1 (ADDRESS_0), U1.2 (ADDRESS_1), U1.3 (ADDRESS_2), U1.8 (GROUND), U2.2 (ADDRESS_1), U2.3 (ADDRESS_2), U2.8 (GROUND), U10.3 (GROUND), U11.3 (GROUND), U12.3 (GROUND), U13.3 (GROUND), U14.3 (GROUND), U15.3 (GROUND), U16.3 (GROUND), U17.3 (GROUND), U18.3 (GROUND), U19.3 (GROUND); also elsewhere on the board
I2C_SCL: U1.14 (I2C_CLOCK), U2.14 (I2C_CLOCK); also elsewhere on the board
I2C_SDA: U1.15 (I2C_DATA), U2.15 (I2C_DATA); also elsewhere on the board
LED_5V: U10.4 (FIVE_VOLTS), U11.4 (FIVE_VOLTS), U12.4 (FIVE_VOLTS), U13.4 (FIVE_VOLTS), U14.4 (FIVE_VOLTS), U15.4 (FIVE_VOLTS), U16.4 (FIVE_VOLTS), U17.4 (FIVE_VOLTS), U18.4 (FIVE_VOLTS), U19.4 (FIVE_VOLTS); also elsewhere on the board
LED_CLOCK_C2_TO_B2: U19.5 (CLOCK_OUT); also elsewhere on the board
LED_CLOCK_D1_TO_E1: U10.2 (CLOCK_IN); also elsewhere on the board
LED_CLOCK_D2_TO_C2: U18.5 (CLOCK_OUT), U19.2 (CLOCK_IN)
LED_CLOCK_E1_TO_F1: U10.5 (CLOCK_OUT), U11.2 (CLOCK_IN)
LED_CLOCK_E2_TO_D2: U17.5 (CLOCK_OUT), U18.2 (CLOCK_IN)
LED_CLOCK_F1_TO_G1: U11.5 (CLOCK_OUT), U12.2 (CLOCK_IN)
LED_CLOCK_F2_TO_E2: U16.5 (CLOCK_OUT), U17.2 (CLOCK_IN)
LED_CLOCK_G1_TO_H1: U12.5 (CLOCK_OUT), U13.2 (CLOCK_IN)
LED_CLOCK_G2_TO_F2: U15.5 (CLOCK_OUT), U16.2 (CLOCK_IN)
LED_CLOCK_H1_TO_H2: U13.5 (CLOCK_OUT), U14.2 (CLOCK_IN)
LED_CLOCK_H2_TO_G2: U14.5 (CLOCK_OUT), U15.2 (CLOCK_IN)
LED_DATA_C2_TO_B2: U19.6 (DATA_OUT); also elsewhere on the board
LED_DATA_D1_TO_E1: U10.1 (DATA_IN); also elsewhere on the board
LED_DATA_D2_TO_C2: U18.6 (DATA_OUT), U19.1 (DATA_IN)
LED_DATA_E1_TO_F1: U10.6 (DATA_OUT), U11.1 (DATA_IN)
LED_DATA_E2_TO_D2: U17.6 (DATA_OUT), U18.1 (DATA_IN)
LED_DATA_F1_TO_G1: U11.6 (DATA_OUT), U12.1 (DATA_IN)
LED_DATA_F2_TO_E2: U16.6 (DATA_OUT), U17.1 (DATA_IN)
LED_DATA_G1_TO_H1: U12.6 (DATA_OUT), U13.1 (DATA_IN)
LED_DATA_G2_TO_F2: U15.6 (DATA_OUT), U16.1 (DATA_IN)
LED_DATA_H1_TO_H2: U13.6 (DATA_OUT), U14.1 (DATA_IN)
LED_DATA_H2_TO_G2: U14.6 (DATA_OUT), U15.1 (DATA_IN)
SQ_A1: U1.4 (P0); also elsewhere on the board
SQ_A2: U1.6 (P2); also elsewhere on the board
SQ_B1: U1.5 (P1); also elsewhere on the board
SQ_B2: U1.7 (P3); also elsewhere on the board
SQ_C1: U1.9 (P4); also elsewhere on the board
SQ_C2: U1.11 (P6); also elsewhere on the board
SQ_D1: U1.10 (P5); also elsewhere on the board
SQ_D2: U1.12 (P7); also elsewhere on the board
SQ_E1: U2.4 (P0); also elsewhere on the board
SQ_E2: U2.6 (P2); also elsewhere on the board
SQ_F1: U2.5 (P1); also elsewhere on the board
SQ_F2: U2.7 (P3); also elsewhere on the board
SQ_G1: U2.9 (P4); also elsewhere on the board
SQ_G2: U2.11 (P6); also elsewhere on the board
SQ_H1: U2.10 (P5); also elsewhere on the board
SQ_H2: U2.12 (P7); also elsewhere on the board

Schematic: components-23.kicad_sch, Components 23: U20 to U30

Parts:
U3: TCA9554DWR; TCA9554
U20, U21, U22, U23, U24, U25, U26, U27, U28, U29, U30: SK9822-A; SK9822

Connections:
+3V3: U3.2 (ADDRESS_1), U3.16 (SUPPLY); also elsewhere on the board
GND: U3.1 (ADDRESS_0), U3.3 (ADDRESS_2), U3.8 (GROUND), U20.3 (GROUND), U21.3 (GROUND), U22.3 (GROUND), U23.3 (GROUND), U24.3 (GROUND), U25.3 (GROUND), U26.3 (GROUND), U27.3 (GROUND), U28.3 (GROUND), U29.3 (GROUND), U30.3 (GROUND); also elsewhere on the board
I2C_SCL: U3.14 (I2C_CLOCK); also elsewhere on the board
I2C_SDA: U3.15 (I2C_DATA); also elsewhere on the board
LED_5V: U20.4 (FIVE_VOLTS), U21.4 (FIVE_VOLTS), U22.4 (FIVE_VOLTS), U23.4 (FIVE_VOLTS), U24.4 (FIVE_VOLTS), U25.4 (FIVE_VOLTS), U26.4 (FIVE_VOLTS), U27.4 (FIVE_VOLTS), U28.4 (FIVE_VOLTS), U29.4 (FIVE_VOLTS), U30.4 (FIVE_VOLTS); also elsewhere on the board
LED_CLOCK_A2_TO_A3: U21.5 (CLOCK_OUT), U22.2 (CLOCK_IN)
LED_CLOCK_A3_TO_B3: U22.5 (CLOCK_OUT), U23.2 (CLOCK_IN)
LED_CLOCK_B2_TO_A2: U20.5 (CLOCK_OUT), U21.2 (CLOCK_IN)
LED_CLOCK_B3_TO_C3: U23.5 (CLOCK_OUT), U24.2 (CLOCK_IN)
LED_CLOCK_C2_TO_B2: U20.2 (CLOCK_IN); also elsewhere on the board
LED_CLOCK_C3_TO_D3: U24.5 (CLOCK_OUT), U25.2 (CLOCK_IN)
LED_CLOCK_D3_TO_E3: U25.5 (CLOCK_OUT), U26.2 (CLOCK_IN)
LED_CLOCK_E3_TO_F3: U26.5 (CLOCK_OUT), U27.2 (CLOCK_IN)
LED_CLOCK_F3_TO_G3: U27.5 (CLOCK_OUT), U28.2 (CLOCK_IN)
LED_CLOCK_G3_TO_H3: U28.5 (CLOCK_OUT), U29.2 (CLOCK_IN)
LED_CLOCK_H3_TO_H4: U29.5 (CLOCK_OUT), U30.2 (CLOCK_IN)
LED_CLOCK_H4_TO_G4: U30.5 (CLOCK_OUT); also elsewhere on the board
LED_DATA_A2_TO_A3: U22.1 (DATA_IN); also elsewhere on the board
LED_DATA_A2_TO_A3_SRC: U21.6 (DATA_OUT); also elsewhere on the board
LED_DATA_A3_TO_B3: U22.6 (DATA_OUT), U23.1 (DATA_IN)
LED_DATA_B2_TO_A2: U20.6 (DATA_OUT), U21.1 (DATA_IN)
LED_DATA_B3_TO_C3: U23.6 (DATA_OUT), U24.1 (DATA_IN)
LED_DATA_C2_TO_B2: U20.1 (DATA_IN); also elsewhere on the board
LED_DATA_C3_TO_D3: U24.6 (DATA_OUT), U25.1 (DATA_IN)
LED_DATA_D3_TO_E3: U25.6 (DATA_OUT), U26.1 (DATA_IN)
LED_DATA_E3_TO_F3: U26.6 (DATA_OUT), U27.1 (DATA_IN)
LED_DATA_F3_TO_G3: U27.6 (DATA_OUT), U28.1 (DATA_IN)
LED_DATA_G3_TO_H3: U28.6 (DATA_OUT), U29.1 (DATA_IN)
LED_DATA_H3_TO_H4: U29.6 (DATA_OUT), U30.1 (DATA_IN)
LED_DATA_H4_TO_G4: U30.6 (DATA_OUT); also elsewhere on the board
SQ_A3: U3.4 (P0); also elsewhere on the board
SQ_A4: U3.6 (P2); also elsewhere on the board
SQ_B3: U3.5 (P1); also elsewhere on the board
SQ_B4: U3.7 (P3); also elsewhere on the board
SQ_C3: U3.9 (P4); also elsewhere on the board
SQ_C4: U3.11 (P6); also elsewhere on the board
SQ_D3: U3.10 (P5); also elsewhere on the board
SQ_D4: U3.12 (P7); also elsewhere on the board

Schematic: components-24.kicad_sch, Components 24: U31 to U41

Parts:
U4: TCA9554DWR; TCA9554
U31, U32, U33, U34, U35, U36, U37, U38, U39, U40, U41: SK9822-A; SK9822

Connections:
+3V3: U4.1 (ADDRESS_0), U4.2 (ADDRESS_1), U4.16 (SUPPLY); also elsewhere on the board
GND: U4.3 (ADDRESS_2), U4.8 (GROUND), U31.3 (GROUND), U32.3 (GROUND), U33.3 (GROUND), U34.3 (GROUND), U35.3 (GROUND), U36.3 (GROUND), U37.3 (GROUND), U38.3 (GROUND), U39.3 (GROUND), U40.3 (GROUND), U41.3 (GROUND); also elsewhere on the board
I2C_SCL: U4.14 (I2C_CLOCK); also elsewhere on the board
I2C_SDA: U4.15 (I2C_DATA); also elsewhere on the board
LED_5V: U31.4 (FIVE_VOLTS), U32.4 (FIVE_VOLTS), U33.4 (FIVE_VOLTS), U34.4 (FIVE_VOLTS), U35.4 (FIVE_VOLTS), U36.4 (FIVE_VOLTS), U37.4 (FIVE_VOLTS), U38.4 (FIVE_VOLTS), U39.4 (FIVE_VOLTS), U40.4 (FIVE_VOLTS), U41.4 (FIVE_VOLTS); also elsewhere on the board
LED_CLOCK_A4_TO_A5: U37.5 (CLOCK_OUT), U38.2 (CLOCK_IN)
LED_CLOCK_A5_TO_B5: U38.5 (CLOCK_OUT), U39.2 (CLOCK_IN)
LED_CLOCK_B4_TO_A4: U36.5 (CLOCK_OUT), U37.2 (CLOCK_IN)
LED_CLOCK_B5_TO_C5: U39.5 (CLOCK_OUT), U40.2 (CLOCK_IN)
LED_CLOCK_C4_TO_B4: U35.5 (CLOCK_OUT), U36.2 (CLOCK_IN)
LED_CLOCK_C5_TO_D5: U40.5 (CLOCK_OUT), U41.2 (CLOCK_IN)
LED_CLOCK_D4_TO_C4: U34.5 (CLOCK_OUT), U35.2 (CLOCK_IN)
LED_CLOCK_D5_TO_E5: U41.5 (CLOCK_OUT); also elsewhere on the board
LED_CLOCK_E4_TO_D4: U33.5 (CLOCK_OUT), U34.2 (CLOCK_IN)
LED_CLOCK_F4_TO_E4: U32.5 (CLOCK_OUT), U33.2 (CLOCK_IN)
LED_CLOCK_G4_TO_F4: U31.5 (CLOCK_OUT), U32.2 (CLOCK_IN)
LED_CLOCK_H4_TO_G4: U31.2 (CLOCK_IN); also elsewhere on the board
LED_DATA_A4_TO_A5: U38.1 (DATA_IN); also elsewhere on the board
LED_DATA_A4_TO_A5_SRC: U37.6 (DATA_OUT); also elsewhere on the board
LED_DATA_A5_TO_B5: U38.6 (DATA_OUT), U39.1 (DATA_IN)
LED_DATA_B4_TO_A4: U36.6 (DATA_OUT), U37.1 (DATA_IN)
LED_DATA_B5_TO_C5: U39.6 (DATA_OUT), U40.1 (DATA_IN)
LED_DATA_C4_TO_B4: U35.6 (DATA_OUT), U36.1 (DATA_IN)
LED_DATA_C5_TO_D5: U40.6 (DATA_OUT), U41.1 (DATA_IN)
LED_DATA_D4_TO_C4: U34.6 (DATA_OUT), U35.1 (DATA_IN)
LED_DATA_D5_TO_E5: U41.6 (DATA_OUT); also elsewhere on the board
LED_DATA_E4_TO_D4: U33.6 (DATA_OUT), U34.1 (DATA_IN)
LED_DATA_F4_TO_E4: U32.6 (DATA_OUT), U33.1 (DATA_IN)
LED_DATA_G4_TO_F4: U31.6 (DATA_OUT), U32.1 (DATA_IN)
LED_DATA_H4_TO_G4: U31.1 (DATA_IN); also elsewhere on the board
SQ_E3: U4.4 (P0); also elsewhere on the board
SQ_E4: U4.6 (P2); also elsewhere on the board
SQ_F3: U4.5 (P1); also elsewhere on the board
SQ_F4: U4.7 (P3); also elsewhere on the board
SQ_G3: U4.9 (P4); also elsewhere on the board
SQ_G4: U4.11 (P6); also elsewhere on the board
SQ_H3: U4.10 (P5); also elsewhere on the board
SQ_H4: U4.12 (P7); also elsewhere on the board

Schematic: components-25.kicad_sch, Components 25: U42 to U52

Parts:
U5: SN74AHCT125DR; AHCT125
U42, U43, U44, U45, U46, U47, U48, U49, U50, U51, U52: SK9822-A; SK9822

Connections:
+5V: U5.10 (BUFFER_3_OUTPUT_ENABLE), U5.13 (BUFFER_4_OUTPUT_ENABLE), U5.14 (SUPPLY); also elsewhere on the board
GND: U5.7 (GROUND), U5.9 (BUFFER_3_INPUT), U5.12 (BUFFER_4_INPUT), U42.3 (GROUND), U43.3 (GROUND), U44.3 (GROUND), U45.3 (GROUND), U46.3 (GROUND), U47.3 (GROUND), U48.3 (GROUND), U49.3 (GROUND), U50.3 (GROUND), U51.3 (GROUND), U52.3 (GROUND); also elsewhere on the board
LED_5V: U42.4 (FIVE_VOLTS), U43.4 (FIVE_VOLTS), U44.4 (FIVE_VOLTS), U45.4 (FIVE_VOLTS), U46.4 (FIVE_VOLTS), U47.4 (FIVE_VOLTS), U48.4 (FIVE_VOLTS), U49.4 (FIVE_VOLTS), U50.4 (FIVE_VOLTS), U51.4 (FIVE_VOLTS), U52.4 (FIVE_VOLTS); also elsewhere on the board
LED_CLK_5V: U5.6 (BUFFER_2_OUTPUT); also elsewhere on the board
LED_CLOCK_B6_TO_A6: U52.5 (CLOCK_OUT); also elsewhere on the board
LED_CLOCK_C6_TO_B6: U51.5 (CLOCK_OUT), U52.2 (CLOCK_IN)
LED_CLOCK_D5_TO_E5: U42.2 (CLOCK_IN); also elsewhere on the board
LED_CLOCK_D6_TO_C6: U50.5 (CLOCK_OUT), U51.2 (CLOCK_IN)
LED_CLOCK_E5_TO_F5: U42.5 (CLOCK_OUT), U43.2 (CLOCK_IN)
LED_CLOCK_E6_TO_D6: U49.5 (CLOCK_OUT), U50.2 (CLOCK_IN)
LED_CLOCK_F5_TO_G5: U43.5 (CLOCK_OUT), U44.2 (CLOCK_IN)
LED_CLOCK_F6_TO_E6: U48.5 (CLOCK_OUT), U49.2 (CLOCK_IN)
LED_CLOCK_G5_TO_H5: U44.5 (CLOCK_OUT), U45.2 (CLOCK_IN)
LED_CLOCK_G6_TO_F6: U47.5 (CLOCK_OUT), U48.2 (CLOCK_IN)
LED_CLOCK_H5_TO_H6: U45.5 (CLOCK_OUT), U46.2 (CLOCK_IN)
LED_CLOCK_H6_TO_G6: U46.5 (CLOCK_OUT), U47.2 (CLOCK_IN)
LED_DATA_B6_TO_A6: U52.6 (DATA_OUT); also elsewhere on the board
LED_DATA_BUF: U5.3 (BUFFER_1_OUTPUT); also elsewhere on the board
LED_DATA_C6_TO_B6: U51.6 (DATA_OUT), U52.1 (DATA_IN)
LED_DATA_D5_TO_E5: U42.1 (DATA_IN); also elsewhere on the board
LED_DATA_D6_TO_C6: U50.6 (DATA_OUT), U51.1 (DATA_IN)
LED_DATA_E5_TO_F5: U42.6 (DATA_OUT), U43.1 (DATA_IN)
LED_DATA_E6_TO_D6: U49.6 (DATA_OUT), U50.1 (DATA_IN)
LED_DATA_F5_TO_G5: U43.6 (DATA_OUT), U44.1 (DATA_IN)
LED_DATA_F6_TO_E6: U48.6 (DATA_OUT), U49.1 (DATA_IN)
LED_DATA_G5_TO_H5: U44.6 (DATA_OUT), U45.1 (DATA_IN)
LED_DATA_G6_TO_F6: U47.6 (DATA_OUT), U48.1 (DATA_IN)
LED_DATA_H5_TO_H6: U45.6 (DATA_OUT), U46.1 (DATA_IN)
LED_DATA_H6_TO_G6: U46.6 (DATA_OUT), U47.1 (DATA_IN)
LED_OE_N: U5.1 (BUFFER_1_OUTPUT_ENABLE), U5.4 (BUFFER_2_OUTPUT_ENABLE); also elsewhere on the board
SPI_CLK_3V3: U5.5 (BUFFER_2_INPUT); also elsewhere on the board
SPI_DATA_3V3: U5.2 (BUFFER_1_INPUT); also elsewhere on the board

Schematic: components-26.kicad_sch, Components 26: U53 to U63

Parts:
U6, U53, U54, U55, U56, U57, U58, U59, U60, U61, U62, U63: SK9822-A; SK9822

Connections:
GND: U6.3 (GROUND), U53.3 (GROUND), U54.3 (GROUND), U55.3 (GROUND), U56.3 (GROUND), U57.3 (GROUND), U58.3 (GROUND), U59.3 (GROUND), U60.3 (GROUND), U61.3 (GROUND), U62.3 (GROUND), U63.3 (GROUND); also elsewhere on the board
LED_5V: U6.4 (FIVE_VOLTS), U53.4 (FIVE_VOLTS), U54.4 (FIVE_VOLTS), U55.4 (FIVE_VOLTS), U56.4 (FIVE_VOLTS), U57.4 (FIVE_VOLTS), U58.4 (FIVE_VOLTS), U59.4 (FIVE_VOLTS), U60.4 (FIVE_VOLTS), U61.4 (FIVE_VOLTS), U62.4 (FIVE_VOLTS), U63.4 (FIVE_VOLTS); also elsewhere on the board
LED_CLK_5V: U6.2 (CLOCK_IN); also elsewhere on the board
LED_CLOCK_A1_TO_B1: U6.5 (CLOCK_OUT); also elsewhere on the board
LED_CLOCK_A6_TO_A7: U53.5 (CLOCK_OUT), U54.2 (CLOCK_IN)
LED_CLOCK_A7_TO_B7: U54.5 (CLOCK_OUT), U55.2 (CLOCK_IN)
LED_CLOCK_B6_TO_A6: U53.2 (CLOCK_IN); also elsewhere on the board
LED_CLOCK_B7_TO_C7: U55.5 (CLOCK_OUT), U56.2 (CLOCK_IN)
LED_CLOCK_C7_TO_D7: U56.5 (CLOCK_OUT), U57.2 (CLOCK_IN)
LED_CLOCK_D7_TO_E7: U57.5 (CLOCK_OUT), U58.2 (CLOCK_IN)
LED_CLOCK_E7_TO_F7: U58.5 (CLOCK_OUT), U59.2 (CLOCK_IN)
LED_CLOCK_F7_TO_G7: U59.5 (CLOCK_OUT), U60.2 (CLOCK_IN)
LED_CLOCK_G7_TO_H7: U60.5 (CLOCK_OUT), U61.2 (CLOCK_IN)
LED_CLOCK_G8_TO_F8: U63.5 (CLOCK_OUT); also elsewhere on the board
LED_CLOCK_H7_TO_H8: U61.5 (CLOCK_OUT), U62.2 (CLOCK_IN)
LED_CLOCK_H8_TO_G8: U62.5 (CLOCK_OUT), U63.2 (CLOCK_IN)
LED_DATA_5V: U6.1 (DATA_IN); also elsewhere on the board
LED_DATA_A1_TO_B1: U6.6 (DATA_OUT); also elsewhere on the board
LED_DATA_A6_TO_A7: U54.1 (DATA_IN); also elsewhere on the board
LED_DATA_A6_TO_A7_SRC: U53.6 (DATA_OUT); also elsewhere on the board
LED_DATA_A7_TO_B7: U54.6 (DATA_OUT), U55.1 (DATA_IN)
LED_DATA_B6_TO_A6: U53.1 (DATA_IN); also elsewhere on the board
LED_DATA_B7_TO_C7: U55.6 (DATA_OUT), U56.1 (DATA_IN)
LED_DATA_C7_TO_D7: U56.6 (DATA_OUT), U57.1 (DATA_IN)
LED_DATA_D7_TO_E7: U57.6 (DATA_OUT), U58.1 (DATA_IN)
LED_DATA_E7_TO_F7: U58.6 (DATA_OUT), U59.1 (DATA_IN)
LED_DATA_F7_TO_G7: U59.6 (DATA_OUT), U60.1 (DATA_IN)
LED_DATA_G7_TO_H7: U60.6 (DATA_OUT), U61.1 (DATA_IN)
LED_DATA_G8_TO_F8: U63.6 (DATA_OUT); also elsewhere on the board
LED_DATA_H7_TO_H8: U61.6 (DATA_OUT), U62.1 (DATA_IN)
LED_DATA_H8_TO_G8: U62.6 (DATA_OUT), U63.1 (DATA_IN)

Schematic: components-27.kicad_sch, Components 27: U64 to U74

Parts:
U7, U64, U65, U66, U67, U68, U69: SK9822-A; SK9822
U70, U71, U72, U73: TCA9554DWR; TCA9554
U74: TPS259474ARPWR; EFUSE

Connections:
+3V3: U70.3 (ADDRESS_2), U70.16 (SUPPLY), U71.1 (ADDRESS_0), U71.3 (ADDRESS_2), U71.16 (SUPPLY), U72.2 (ADDRESS_1), U72.3 (ADDRESS_2), U72.16 (SUPPLY), U73.1 (ADDRESS_0), U73.2 (ADDRESS_1), U73.3 (ADDRESS_2), U73.16 (SUPPLY); also elsewhere on the board
+5V: U74.6 (OUTPUT); also elsewhere on the board
DC_FUSED: U74.5 (INPUT); also elsewhere on the board
EFUSE_DVDT: U74.7 (SLEW_RATE); also elsewhere on the board
EFUSE_EN: U74.1 (ENABLE_UVLO); also elsewhere on the board
EFUSE_ILM: U74.9 (CURRENT_LIMIT); also elsewhere on the board
EFUSE_ITIMER: U74.10 (OVERCURRENT_TIMER); also elsewhere on the board
EFUSE_OVLO: U74.2 (OVERVOLTAGE_LOCKOUT), U74.4 (POWER_GOOD_THRESHOLD); also elsewhere on the board
GND: U7.3 (GROUND), U64.3 (GROUND), U65.3 (GROUND), U66.3 (GROUND), U67.3 (GROUND), U68.3 (GROUND), U69.3 (GROUND), U70.1 (ADDRESS_0), U70.2 (ADDRESS_1), U70.8 (GROUND), U71.2 (ADDRESS_1), U71.8 (GROUND), U72.1 (ADDRESS_0), U72.8 (GROUND), U73.8 (GROUND), U74.8 (GROUND); also elsewhere on the board
I2C_SCL: U70.14 (I2C_CLOCK), U71.14 (I2C_CLOCK), U72.14 (I2C_CLOCK), U73.14 (I2C_CLOCK); also elsewhere on the board
I2C_SDA: U70.15 (I2C_DATA), U71.15 (I2C_DATA), U72.15 (I2C_DATA), U73.15 (I2C_DATA); also elsewhere on the board
LED_5V: U7.4 (FIVE_VOLTS), U64.4 (FIVE_VOLTS), U65.4 (FIVE_VOLTS), U66.4 (FIVE_VOLTS), U67.4 (FIVE_VOLTS), U68.4 (FIVE_VOLTS), U69.4 (FIVE_VOLTS); also elsewhere on the board
LED_CLOCK_A1_TO_B1: U7.2 (CLOCK_IN); also elsewhere on the board
LED_CLOCK_B1_TO_C1: U7.5 (CLOCK_OUT); also elsewhere on the board
LED_CLOCK_B8_TO_A8: U68.5 (CLOCK_OUT), U69.2 (CLOCK_IN)
LED_CLOCK_C8_TO_B8: U67.5 (CLOCK_OUT), U68.2 (CLOCK_IN)
LED_CLOCK_D8_TO_C8: U66.5 (CLOCK_OUT), U67.2 (CLOCK_IN)
LED_CLOCK_E8_TO_D8: U65.5 (CLOCK_OUT), U66.2 (CLOCK_IN)
LED_CLOCK_F8_TO_E8: U64.5 (CLOCK_OUT), U65.2 (CLOCK_IN)
LED_CLOCK_G8_TO_F8: U64.2 (CLOCK_IN); also elsewhere on the board
LED_DATA_A1_TO_B1: U7.1 (DATA_IN); also elsewhere on the board
LED_DATA_B1_TO_C1: U7.6 (DATA_OUT); also elsewhere on the board
LED_DATA_B8_TO_A8: U68.6 (DATA_OUT), U69.1 (DATA_IN)
LED_DATA_C8_TO_B8: U67.6 (DATA_OUT), U68.1 (DATA_IN)
LED_DATA_D8_TO_C8: U66.6 (DATA_OUT), U67.1 (DATA_IN)
LED_DATA_E8_TO_D8: U65.6 (DATA_OUT), U66.1 (DATA_IN)
LED_DATA_F8_TO_E8: U64.6 (DATA_OUT), U65.1 (DATA_IN)
LED_DATA_G8_TO_F8: U64.1 (DATA_IN); also elsewhere on the board
SQ_A5: U70.4 (P0); also elsewhere on the board
SQ_A6: U70.6 (P2); also elsewhere on the board
SQ_A7: U72.4 (P0); also elsewhere on the board
SQ_A8: U72.6 (P2); also elsewhere on the board
SQ_B5: U70.5 (P1); also elsewhere on the board
SQ_B6: U70.7 (P3); also elsewhere on the board
SQ_B7: U72.5 (P1); also elsewhere on the board
SQ_B8: U72.7 (P3); also elsewhere on the board
SQ_C5: U70.9 (P4); also elsewhere on the board
SQ_C6: U70.11 (P6); also elsewhere on the board
SQ_C7: U72.9 (P4); also elsewhere on the board
SQ_C8: U72.11 (P6); also elsewhere on the board
SQ_D5: U70.10 (P5); also elsewhere on the board
SQ_D6: U70.12 (P7); also elsewhere on the board
SQ_D7: U72.10 (P5); also elsewhere on the board
SQ_D8: U72.12 (P7); also elsewhere on the board
SQ_E5: U71.4 (P0); also elsewhere on the board
SQ_E6: U71.6 (P2); also elsewhere on the board
SQ_E7: U73.4 (P0); also elsewhere on the board
SQ_E8: U73.6 (P2); also elsewhere on the board
SQ_F5: U71.5 (P1); also elsewhere on the board
SQ_F6: U71.7 (P3); also elsewhere on the board
SQ_F7: U73.5 (P1); also elsewhere on the board
SQ_F8: U73.7 (P3); also elsewhere on the board
SQ_G5: U71.9 (P4); also elsewhere on the board
SQ_G6: U71.11 (P6); also elsewhere on the board
SQ_G7: U73.9 (P4); also elsewhere on the board
SQ_G8: U73.11 (P6); also elsewhere on the board
SQ_H5: U71.10 (P5); also elsewhere on the board
SQ_H6: U71.12 (P7); also elsewhere on the board
SQ_H7: U73.10 (P5); also elsewhere on the board
SQ_H8: U73.12 (P7); also elsewhere on the board

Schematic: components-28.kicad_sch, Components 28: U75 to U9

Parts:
U8, U9: SK9822-A; SK9822
U75: SN74LVC1G97DBVR; LED_ENABLE_GATE

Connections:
+5V: U75.3 (INPUT_0), U75.5 (SUPPLY); also elsewhere on the board
GND: U8.3 (GROUND), U9.3 (GROUND), U75.2 (GROUND); also elsewhere on the board
LED_5V: U8.4 (FIVE_VOLTS), U9.4 (FIVE_VOLTS); also elsewhere on the board
LED_CLOCK_B1_TO_C1: U8.2 (CLOCK_IN); also elsewhere on the board
LED_CLOCK_C1_TO_D1: U8.5 (CLOCK_OUT), U9.2 (CLOCK_IN)
LED_CLOCK_D1_TO_E1: U9.5 (CLOCK_OUT); also elsewhere on the board
LED_DATA_B1_TO_C1: U8.1 (DATA_IN); also elsewhere on the board
LED_DATA_C1_TO_D1: U8.6 (DATA_OUT), U9.1 (DATA_IN)
LED_DATA_D1_TO_E1: U9.6 (DATA_OUT); also elsewhere on the board
LED_EN_N: U75.1 (INPUT_1); also elsewhere on the board
LED_OE_N: U75.4 (OUTPUT); also elsewhere on the board
LED_SW_GATE: U75.6 (INPUT_2); also elsewhere on the board

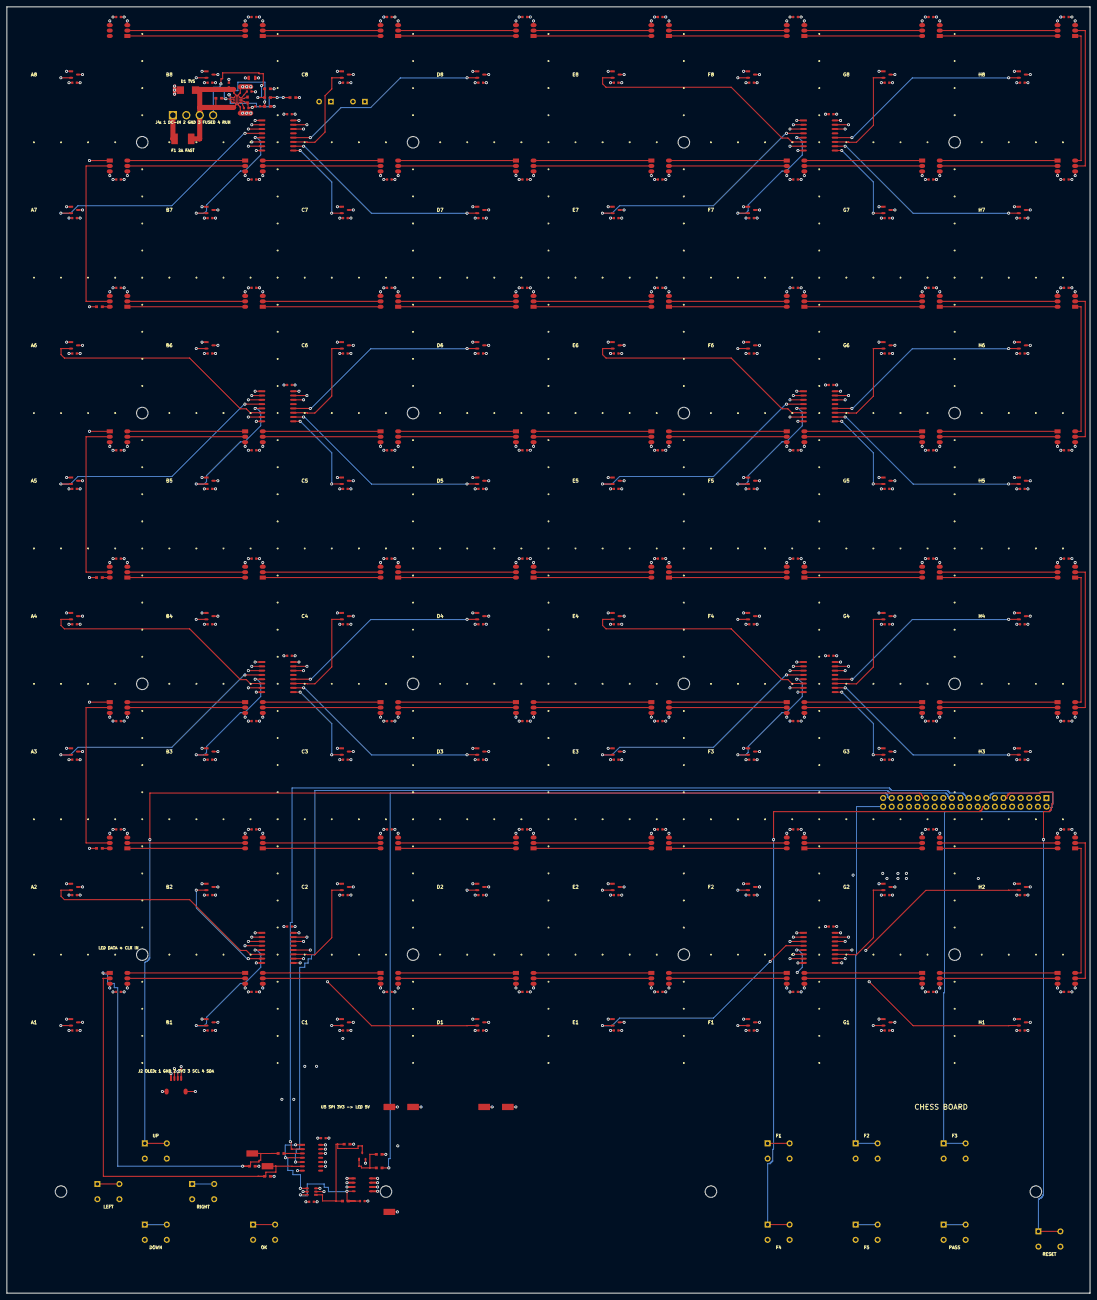
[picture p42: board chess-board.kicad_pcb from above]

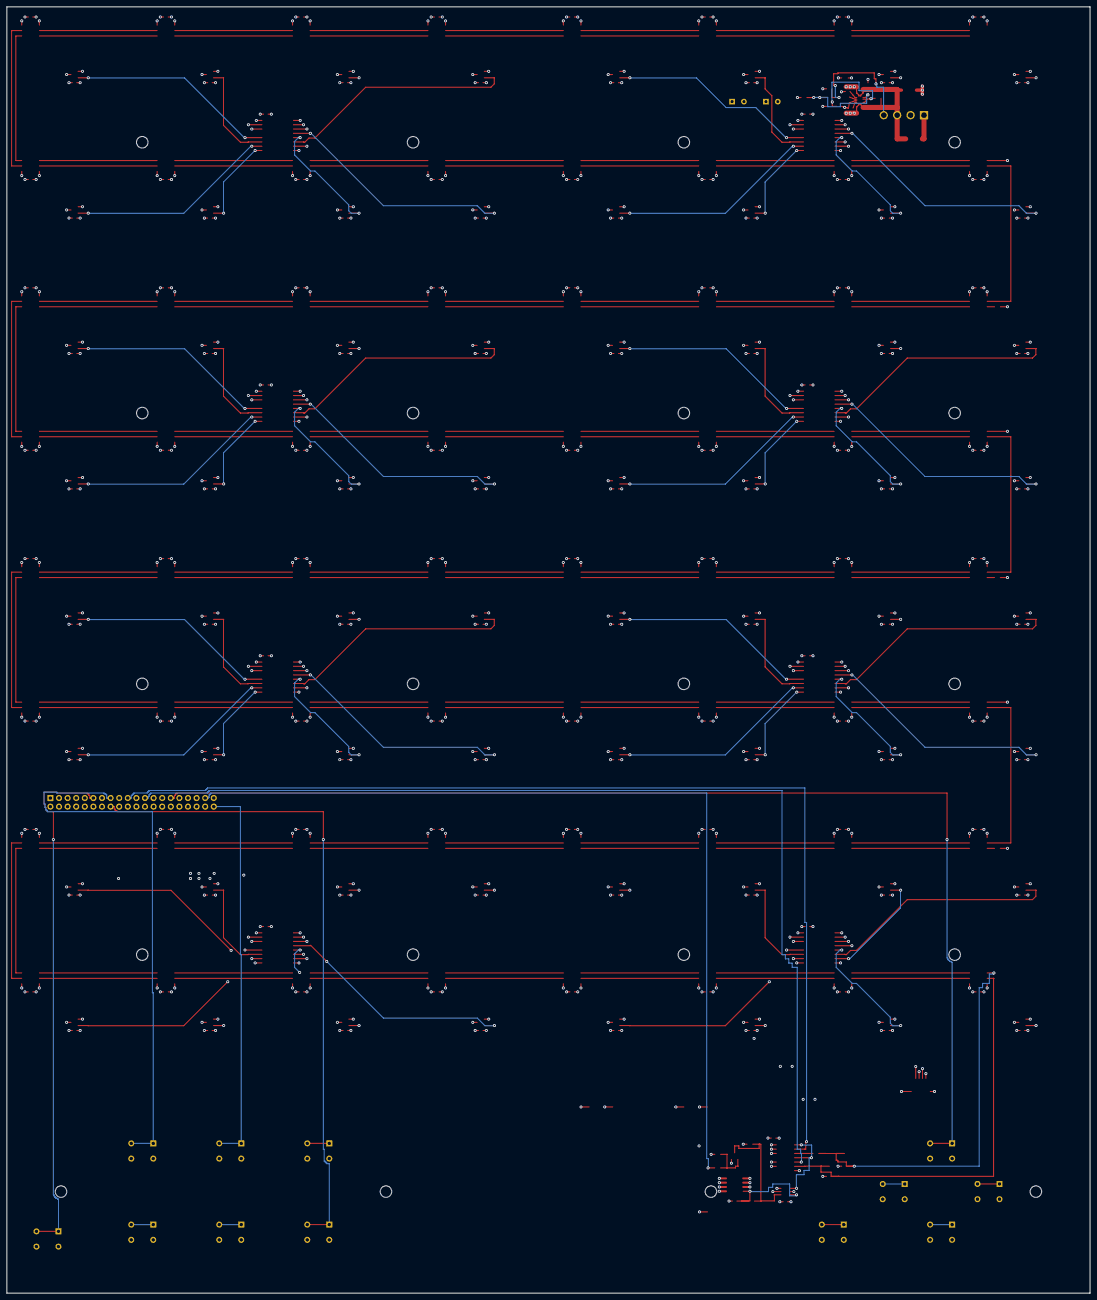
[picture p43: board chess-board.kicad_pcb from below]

Board: 8 copper layers, 320.0 x 380.0 mm, 347 parts (4 on the bottom side), 229 nets.

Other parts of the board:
H1, H2, H3, H4, H5, H6, H7, H8, H9, H10, H11, H12, H13, H14, H15, H16, H17, H18, H19, H20: Mounting hole

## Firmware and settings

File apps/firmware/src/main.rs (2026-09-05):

use std::{env, io};

use firmware::runtime::Firmware;
use logger::{LevelFilter, implementations::SystemdLogger, info, register};

static LOGGER: SystemdLogger = SystemdLogger::new(LevelFilter::Info);

fn main() -> io::Result<()> {
    if env::args().nth(1).as_deref() == Some("--version") {
        println!("firmware {}", env!("CARGO_PKG_VERSION"));
        return Ok(());
    }

    register(&LOGGER).map_err(|_| io::Error::other("firmware logger already registered"))?;
    info!("starting firmware {}", env!("CARGO_PKG_VERSION"));

    tokio::runtime::Builder::new_current_thread()
        .enable_all()
        .build()?
        .block_on(async {
            let mut firmware = Firmware::start()?;
            // Physical adapters will attach to firmware.events().
            firmware.wait().await
        })
}

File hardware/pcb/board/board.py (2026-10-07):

"""The chessboard declared using concrete components and the circuit harness.

`Board()` declares all 327 PCB components and their complete connections.
Coordinates use the physical PCB centre; shared playing-area coordinates are
translated by `_placement`. `generate.py` exports its KiCad project, connection
schematics, PCB, BOM, netlist and review reports. This definition owns physical
features and design rules; `wiring.py` declares routing intent for the harness.
Board tests model sensing and button behavior; full electrical and physical
release validation remain pending.
"""

from pcb.components.capacitors.capacitor_1_microfarad import Capacitor1Microfarad
from pcb.components.capacitors.capacitor_1_nanofarad import Capacitor1Nanofarad
from pcb.components.capacitors.capacitor_10_microfarad import Capacitor10Microfarad
from pcb.components.capacitors.capacitor_10_nanofarad import Capacitor10Nanofarad
from pcb.components.capacitors.capacitor_100_nanofarad import Capacitor100Nanofarad
from pcb.components.capacitors.polarized_capacitor_560_microfarad import (
    PolarizedCapacitor560Microfarad,
)
from pcb.components.connectors.host_gpio_socket_40_pin import HostGpioSocket40Pin
from pcb.components.connectors.oled_connector_4_pin import OledConnector4Pin
from pcb.components.connectors.power_connector_4_pin import PowerConnector4Pin
from pcb.components.connectors.test_point import TestPoint
from pcb.components.gpio_expanders.gpio_expander_8_bit import GpioExpander8Bit
from pcb.components.hall_sensors.hall_sensor import HallSensor
from pcb.components.leds.clocked_rgb_led import ClockedRgbLed
from pcb.components.level_shifters.logic_level_shifter_4_channel import (
    LogicLevelShifter4Channel,
)
from pcb.components.logic_gates.led_enable_logic_gate import LedEnableLogicGate
from pcb.components.mosfets.led_power_mosfet import LedPowerMosfet
from pcb.components.mosfets.led_switch_driver_mosfet import LedSwitchDriverMosfet
from pcb.components.power.electronic_fuse import ElectronicFuse
from pcb.components.power.fuse_2_ampere import Fuse2Ampere
from pcb.components.resistors.precision_resistor_169_kilohm import (
    PrecisionResistor169Kilohm,
)
from pcb.components.resistors.precision_resistor_604_kilohm import (
    PrecisionResistor604Kilohm,
)
from pcb.components.resistors.resistor_1_65_kilohm import Resistor1Point65Kilohm
from pcb.components.resistors.resistor_1_kilohm import Resistor1Kilohm
from pcb.components.resistors.resistor_10_kilohm import Resistor10Kilohm
from pcb.components.resistors.resistor_56_ohm import Resistor56Ohm
from pcb.components.resistors.resistor_100_kilohm import Resistor100Kilohm
from pcb.components.resistors.resistor_261_kilohm import Resistor261Kilohm
from pcb.components.switches.tactile_button import TactileButton
from pcb.components.tvs_diodes.bidirectional_tvs_12_volt import BidirectionalTvs12Volt
from pcb.harness import (
    BoardOutline,
    Circuit,
    CopperLayer,
    Net,
    NetRoute,
    NoConnect,
    Placement,
    Point,
)
from pcb.harness.base.geometry import Side
from pcb.harness.base.pcbnew.design_rules import DesignRules
from pcb.harness.base.pcbnew.layout import BoardLayout, Label, Line, MountingHole, Plane
from pcb.harness.base.pcbnew.routing.settings import RoutingSettings
from shared import dimensions, wiring
from shared.electronics import Tca9554Pin
from shared.panel_buttons import PANEL_BUTTONS
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

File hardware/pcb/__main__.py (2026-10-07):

"""Command-line entry for the composed board and harness-based generation."""

import argparse

from pcb.board.board import Board
from pcb.board.generate import generate
from pcb.harness.checks.run import check


def main() -> None:
    parser = argparse.ArgumentParser(description=__doc__)
    parser.add_argument("command", choices=("generate", "check", "review", "release"))

    class Options(argparse.Namespace):
        command: str = ""

    args = parser.parse_args(namespace=Options())
    if args.command == "release":
        parser.exit(
            1,
            "Fabrication release is unavailable: manufacturing reassessment, electrical checks and physical evidence are pending.\n",
        )
    if args.command in ("check", "review"):
        check(Board(), electrical=args.command == "check")
    if args.command in ("generate", "review"):
        print(generate())


if __name__ == "__main__":
    main()

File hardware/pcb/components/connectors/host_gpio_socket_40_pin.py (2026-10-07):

"""Raspberry Pi Zero 2 W 2x20 socket (PPPC202LFBN-RC).

Package geometry follows the reviewed production definition for PI_ZERO_HEADER.
Electrical simulation is unavailable unless a model is explicitly declared.
"""

from pcb.harness import (
    BoardComponent,
    BoardRegistry,
    ComponentDefinition,
    Courtyard,
    LandPattern,
    Net,
    NoConnect,
    Pad,
    PadKind,
    PadShape,
    Placement,
    Point,
    Product,
)
from shared.components import PI_ZERO_HEADER
from shared.dimensions.case import PI_HEADER_BODY_MM
from shared.electronics.raspberry_pi_header import RaspberryPiHeaderPin

PI_ZERO_HEADER_DEFINITION = ComponentDefinition(
    product=Product(
        key=PI_ZERO_HEADER.key,
        manufacturer=PI_ZERO_HEADER.manufacturer,
        part_number=PI_ZERO_HEADER.mpn,
        package=PI_ZERO_HEADER.package,
        body_mm=(PI_HEADER_BODY_MM[1], PI_HEADER_BODY_MM[0], PI_HEADER_BODY_MM[2]),
        datasheet=PI_ZERO_HEADER.datasheet,
    ),
    pin_type=RaspberryPiHeaderPin,
    courtyard=Courtyard(5.5, 51.5),
    land_pattern=LandPattern(
        RaspberryPiHeaderPin,
        (
            Pad(
                RaspberryPiHeaderPin.BUTTON_F2_GPIO21,
                Point(1.27, -24.13),
                1.82,
                1.82,
                shape=PadShape.CIRCLE,
                kind=PadKind.THROUGH_HOLE,
                drill_mm=1.02,
                solder_mask_margin_mm=0.05,
            ),
            Pad(
                RaspberryPiHeaderPin.GROUND_39,
                Point(-1.27, -24.13),
                1.82,
                1.82,
                shape=PadShape.CIRCLE,
                kind=PadKind.THROUGH_HOLE,
                drill_mm=1.02,
                solder_mask_margin_mm=0.05,
            ),
            Pad(
                RaspberryPiHeaderPin.BUTTON_F1_GPIO20,
                Point(1.27, -21.59),
                1.82,
                1.82,
                shape=PadShape.CIRCLE,
                kind=PadKind.THROUGH_HOLE,
                drill_mm=1.02,
                solder_mask_margin_mm=0.05,
            ),
            Pad(
                RaspberryPiHeaderPin.LED_EN_GPIO26,
                Point(-1.27, -21.59),
                1.82,
                1.82,
                shape=PadShape.CIRCLE,
                kind=PadKind.THROUGH_HOLE,
                drill_mm=1.02,
                solder_mask_margin_mm=0.05,
            ),
            Pad(
                RaspberryPiHeaderPin.BUTTON_OK_GPIO16,
                Point(1.27, -19.05),
                1.82,
                1.82,
                shape=PadShape.CIRCLE,
                kind=PadKind.THROUGH_HOLE,
                drill_mm=1.02,
                solder_mask_margin_mm=0.05,
            ),
            Pad(
                RaspberryPiHeaderPin.BUTTON_PASS_GPIO19,
                Point(-1.27, -19.05),
                1.82,
                1.82,
                shape=PadShape.CIRCLE,
                kind=PadKind.THROUGH_HOLE,
                drill_mm=1.02,
                solder_mask_margin_mm=0.05,
            ),
            Pad(
                RaspberryPiHeaderPin.GROUND_34,
                Point(1.27, -16.51),
                1.82,
                1.82,
                shape=PadShape.CIRCLE,
                kind=PadKind.THROUGH_HOLE,
                drill_mm=1.02,
                solder_mask_margin_mm=0.05,
            ),
            Pad(
                RaspberryPiHeaderPin.BUTTON_RIGHT_GPIO13,
                Point(-1.27, -16.51),
                1.82,
                1.82,
                shape=PadShape.CIRCLE,
                kind=PadKind.THROUGH_HOLE,
                drill_mm=1.02,
                solder_mask_margin_mm=0.05,
            ),
            Pad(
                RaspberryPiHeaderPin.BUTTON_LEFT_GPIO12,
                Point(1.27, -13.97),
                1.82,
                1.82,
                shape=PadShape.CIRCLE,
                kind=PadKind.THROUGH_HOLE,
                drill_mm=1.02,
                solder_mask_margin_mm=0.05,
            ),
            Pad(
                RaspberryPiHeaderPin.BUTTON_DOWN_GPIO6,
                Point(-1.27, -13.97),
                1.82,
                1.82,
                shape=PadShape.CIRCLE,
                kind=PadKind.THROUGH_HOLE,
                drill_mm=1.02,
                solder_mask_margin_mm=0.05,
            ),
            Pad(
                RaspberryPiHeaderPin.GROUND_30,
                Point(1.27, -11.43),
                1.82,
                1.82,
                shape=PadShape.CIRCLE,
                kind=PadKind.THROUGH_HOLE,
                drill_mm=1.02,
                solder_mask_margin_mm=0.05,
            ),
            Pad(
                RaspberryPiHeaderPin.BUTTON_UP_GPIO5,
                Point(-1.27, -11.43),
                1.82,
                1.82,
                shape=PadShape.CIRCLE,
                kind=PadKind.THROUGH_HOLE,
                drill_mm=1.02,
                solder_mask_margin_mm=0.05,
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

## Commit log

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2026-08-28 feat(core): add fixed-capacity ring buffer
    [mod.rs]
2026-08-28 feat(core): add fixed-capacity stack
    [mod.rs]
2026-08-29 feat(electronics): generate schematics and BOM from Python with Schemdraw
    The electronics design had no reproducible drawing path: KiCad sheets needed a
    KiCad install (or a Docker image) to render, and the parts list was maintained
    separately from the design.
    Make Python the single source of truth. Schemdraw draws every project, and the
    bill of materials is counted from the symbols actually placed, so quantities
    cannot drift from the drawings. Components are one module each and register
    themselves, so adding a part needs no edits elsewhere.
    Generated artefacts (SVG, PNG, bom.md) sit at the top of hardware/electronics;
    source lives in components/, blocks/, core/ and projects/.
2026-08-29 fix(electronics): make generated drawings reproducible
    Matplotlib stamps the current time into SVG metadata and derives element ids
    from a random per-run salt, so a committed drawing showed as modified after
    every build even when the design had not changed.
    Pin the hash salt and rewrite the date from the sheet, so rebuilding is a
    no-op unless the schematic itself changed.
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2026-08-29 fix(hardware): run each hardware tool as one sequential job
    A bare ./tools/cad or ./tools/electronics should install if needed, test,
    then generate, so the path people actually invoke is the complete local job.
2026-08-29 fix(hardware): drop cad and electronics subcommands
    Each script is one sequential job. Extra arguments error. The quality
    gate runs the full scripts, so CAD regenerates on check.
2026-08-29 fix(ci): prebuild the devcontainer then run jobs in parallel
    Bake Blender and Schemdraw into the image so later CI pulls layers instead
    of downloading toolchains per job. CAD, electronics, and Rust then run
    side by side through the Dev Container CLI.
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2026-08-29 feat(chess): replace raw offset integers with file and rank types
    [mod.rs]
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2026-08-31 refactor(chess): centralize source-less error implementations
    [mod.rs]
2026-09-01 fix(pcb): correct reviewed component pinouts
    [chess-board.dsn, chess-board.kicad_pcb, chess-board.kicad_sch]
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2026-09-01 fix(pcb): harden fabrication release design
    [assembly-bom.csv, chess-board.dsn, chess-board.kicad_pcb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]
2026-09-01 feat(hardware): gate CAD and PCB Python with Ruff
    Add the standard Ruff lint and format checks for hardware Python so unused
    code and style drift fail locally, on pre-commit, and in CI.
2026-09-01 Fix executable modes for PCB scripts
    [configure_project.py]
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2026-09-18 CAD: publish generated artifacts atomically (#18)
    * feat: publish CAD outputs as complete sets
    * Fix: Include build_support.py in source hashes
    The staged_output function was extracted to hardware/build_support.py but
    the source_hashes() calculation didn't include the new file. This left the
    publication helper outside the mixed-version check and manifest recording.
    * test: cover publication helper source hash
    ---------
    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
2026-09-18 Refactor hardware square wiring into value objects (#21)
    * refactor(hardware): model square wiring assignments
    * Fix board generation: import FILES from hall_banks instead of wiring
    The FILES constant was moved to hall_banks.py in the refactor, but
    square_centres() in board.py was still trying to access wiring.FILES,
    causing an AttributeError during board generation.
    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
    [board.py]
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2026-09-21 test(menu): cover external user journeys (#47)
    * test(menu): cover external user journeys
    * test(menu): restore product callback dispatch coverage
    Add test exercising handle_and_dispatch with MAIN_MENU and
    ChessboardCallbacks to ensure callback dispatch chain is verified.
    Addresses review feedback to maintain product integration coverage
    alongside new externally-defined journey tests.
    * style(menu): sort imports alphabetically
    Fix rustfmt check by ordering imports alphabetically.
    Co-a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
    [main.rs]
2026-09-21 refactor(menu): move product definition to firmware (#43)
    * refactor(menu): move product definition to firmware
    * fix(menu): remove product-specific test dependencies
    Remove ChessboardAction, ChessboardCallbacks, and MAIN_MENU imports
    from menu crate tests. These types were moved to the firmware crate
    as part of the refactoring that makes menu a product-neutral library.
    The product_callback_dispatch_reaches_firmware_implementations test
    has been removed as it tested product-specific behavior that now
    belongs in firmware tests.
    ---------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
    [main.rs]
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2026-10-05 test(firmware): cover validation, event and button edge cases
    Adds unit tests inside the existing test modules; no production code
    changes.
    - Ssid and Passphrase boundaries (byte vs character length, control
    characters, hex keys) and secret redaction in Debug output.
    - Event bus lag, close and drain; direct channel send-after-drop.
    - Debounce candidate replacement and press/release/press chains.
    - Button polling: two held buttons, per-pin isolation, dropped
    subscriptions, failing first and persistent reads, and a failed read
    restarting the debounce window (asserted strictly between the broken
    and correct press times).
    [buttons.rs]
2026-10-05 test(firmware): replace Linux VM e2e tests with fakes
    The Docker/QEMU tests booted Ubuntu guests with simulated radios and GPIO
    chips. They were slow, ran inside `cargo test -p firmware` (and so in
    precommit), and proved little about the Pi. The real test of the Linux
    adapters is the board.
    - Delete tests/e2e (testcontainers, cloud-init VM, probe binary); the
    firmware package no longer builds test code or depends on
    testcontainers.
    - Move the in-process tests to tests/runtime. Menu journeys navigate by
    Request, derived from the product menu, instead of counted presses,
    and cover non-menu buttons, releases, navigation edges and all 64
    squares.
    - Put Connectivity behind a crate-priv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
    [gpio.rs, main.rs, mod.rs]
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2026-10-06 feat(shared): add TPS259474 eFuse and 560 uF cap, drop 1000 uF cap
    Cite Switchcraft 722A and TL1105 datasheet sizes in the jack and button specs; the 560 uF Rubycon ZLJ replaces the 1000 uF LED-rail bulk cap.
    - hardware/shared/components/button.py
    - hardware/shared/components/cap_1000u.py
    - hardware/shared/components/cap_100n.py
    - hardware/shared/components/cap_10u.py
    - hardware/shared/components/cap_560u.py
    - hardware/shared/components/efuse.py
    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
2026-10-06 feat(shared): add harness wires and LED rail switch product specs
    Four-colour 18 AWG and PTFE 28 AWG wires so a cavity swap is visible (reviewer-s3c M-a); Si4403DDY switch, BSS138 driver, LVC1G97 gate.
    - hardware/shared/components/led_switch.py
    - hardware/shared/components/micro_sd.py
    - hardware/shared/components/oled_header.py
    - hardware/shared/components/oled_module.py
    - hardware/shared/components/pi_zero_2_w.py
    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
2026-10-06 feat(shared): add LED package tolerance, widen case frame (part 1/3)
    Opsco SK9822-A 5.4 x 5.0 x 1.6 mm body replaces the WS2812B comment; CASE_FRAME_WIDTH_MM 10 -> 12 for a solid outboard wall.
    - hardware/shared/dimensions/__init__.py
    - hardware/shared/dimensions/board.py
    - hardware/shared/dimensions/case.py
    [board.py]
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2026-10-06 feat(shared): derive Pi centre, vent slots and microSD slot (part 3/3)
    Replace the rear jack/rocker apertures with Pi-bay derived dimensions taken from the RP-008358 drawing.
    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
2026-10-06 feat(shared): validate PCB pocket and ledge fit (part 2/5)
    Rectangle-outside helper and board-in-pocket check replace the old plate-screw ledge check.
    - hardware/shared/dimensions/validation.py
2026-10-06 feat(shared): validate plate rim and button clearances (part 3/5)
    Screw pilot/head margins on the rim; stems stand proud of the bezel and housings clear the strip.
    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
2026-10-06 feat(pcb): add button label offset, move capacitor lands to Murata table
    Reflow land sizes b/c from Murata JEMCGC-2701X p25 Table 2; electrolytic part replaced for the 560 uF cap.
    - hardware/pcb/definition/parts/capacitors.py
    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
2026-10-06 feat(pcb): add BSS138 driver land, cite OLED header source
    onsemi 318 Issue AU footprint (0.56 x 0.95 pads, centres +/-0.975) supersedes the older 0.80 x 0.90 land (S6b manufacturing review).
    - hardware/pcb/definition/parts/oled_header.py
    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
2026-10-06 feat(pcb): validate part bindings, add J4 JST VH power header land
    Guards against a wrong footprint or pinout for the product; B4PS-VH holes 1.65 mm at 3.96 pitch from catalogue p4.
    - hardware/pcb/definition/parts/power_header.py
    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
2026-10-06 feat(pcb): switch TVS footprint to SMBJ12CA with 2.30 mm pad gap
    Gap centred on the Littelfuse foot per the S4c manufacturing review; replaces the 6.8 V TVS binding.
    - hardware/pcb/definition/parts/tvs_diode.py
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2026-10-06 feat(pcb): finish LED switch gate logic, rework power (part 1/3)
    Gate = LED_EN_N OR the LVC1G97 output per SCES416N Table 1 (reviewer finding); power assembly now counts 20 parts.
    - hardware/pcb/definition/assemblies/power.py
    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
2026-10-06 feat(pcb): replace jack and switch with J4 and U74 eFuse (part 2/3)
    Panel jack and rocker are wired off board; place J4, F1, SMBJ12CA, U74 and the 560 uF bulk caps.
    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
2026-10-06 feat(pcb): connect J4 pads, R8 wetting load and C144 filter (part 5/6)
    Fixed offsets from U74 because the 0.2 mm pad gaps are too tight for the grid router.
    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
2026-10-06 feat(pcb): clear pad mask web in escape vias; raise PCBWay minimums
    Escape distance is at least half the pad plus the mask-web reach; fab minimums 0.1 -> 0.127 trace / 0.152 clearance per the 2026-10-06 manufacturing review.
    - hardware/pcb/definition/rules.py
    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
2026-10-06 feat(pcb): document CLI errors and build output redirect (part 1/3)
    PCB_OUTPUT redirects tests away from checked-in generated/; expected failures print one line and exit 1.
    - hardware/pcb/__main__.py
    - hardware/pcb/build.py
    [__main__.py]
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2026-10-06 feat(pcb): fix random seed and board floors in native setup (part 2/3)
    Seed spells CHES so KiCad UUIDs are reproducible; mask dam and silk spacing use fab minimums.
    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
2026-10-06 feat(pcb): add rank-turn terminators to schematic, doc symbol UUIDs
    R9-style terminators join the LED sheet; fixed uuid5 namespace documented since changing it re-keys schematic and board.
    - hardware/pcb/definition/output/symbols.py
    - hardware/pcb/definition/validation.py
    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
2026-10-06 feat(pcb): add PR report summary and pcbnew type stubs (part 2/2)
    Fallback when a changed file exposes no tracked facts; stubs for Flip, ERROR_INSIDE, zone connections.
    - hardware/pcb/typings/pcbnew/__init__.pyi
    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
2026-10-06 test(pcb): assert J4/F1/U74 power path; start decoupling test
    Jack tip -> J4.1 -> F1 -> DC_FUSED, RUN enables U74, C144 filters OVLO, R4/R6/R5 divider guards swapped-polarity or unfused wiring.
    - hardware/pcb/tests/board/test_decoupling.py
    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
2026-10-06 test(pcb): parse DRC violations and rule exception scopes (part 2/5)
    Reads the loosened (min ..mm) rules and the footprints they name.
    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
2026-10-06 test(pcb): require the clearance exception only at U74 (part 3/5)
    Run DRC with board-wide rules; every violation must lie within U74's courtyard plus escape margin (S4c r-m2).
    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
2026-10-06 test(pcb): check flipped rotation, J4 hole size; start firmware pin test
    Back-side parts report 180 - rotation; J4 holes 1.65 mm at 3.96 pitch; J3 reference removed.
    - hardware/pcb/tests/board/test_firmware_pins.py
    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
2026-10-06 test(pcb): compare firmware pin enum with the Pi header table (part 4/4)
    Fail if pins.rs disagrees with the golden header or the board netlist.
    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
2026-10-06 test(pcb): check strapped pins, drawing view, pad positions (part 9/11)
    Internally connected pins (e.g. TL1105 1-2) must share a net; each binding declares which side its drawing is seen from.
    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
2026-10-06 test(pcb): detect contention, missing drivers and host pulls (part 4/5)
    Checks each net has exactly the drivers its pin types allow and supply pins match their rails.
    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
2026-10-06 test(pcb): check routing step clearance; start solder test (part 1/3)
    Reviewer m2: free cells are not enough, each step between them must keep track clearance from foreign copper.
    - hardware/pcb/tests/board/test_selective_solder.py
    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
2026-10-06 test(pcb): reject duplicate bank addresses; start build-pipeline test
    A duplicate I2C address, reference or position would collide on the board; failed generator leaves published output untouched.
    - hardware/pcb/tests/pipeline/test_build.py
    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
2026-10-06 test(pcb): read resistor values from the board in harness (part 2/9)
    Nominal ohms and tolerance come from the placed footprint; the old power-path net lookup goes (J3/SW13 left the board).
    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
2026-10-06 test(pcb): model R9 source termination in SPICE harness (part 4/9)
    S5: the data channel reaches the first LED through R9; node expressions replaced by net-endpoint lookups.
    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
2026-10-06 test(pcb): add per-button SPICE rows with Pi pull-ups (part 7/9)
    Each panel button resolves its host pin and signal net from the netlist.
    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
2026-10-06 test(pcb): add Mean Well supply datasheet figures (part 2/4)
    5 V 2 A rating, overload and over-voltage behaviour; tolerances where no GST12A mirror exists use the GST25B family sheet (ASSUMPTION 'GST12A05 output').
    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
2026-10-06 test(pcb): add eFuse model thresholds and dVdt gain (part 2/6)
    UVP 2.53 V, 2000/SR dVdt fit and a generic ESD pin clamp for reverse-polarity cases.
    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
2026-10-06 test(pcb): add eFuse subcircuit per datasheet corner (part 4/6)
    Ron, current limit and short-circuit ratio build the IN/OUT/EN/OVLO/GND subcircuit.
    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
2026-10-06 test(pcb): compute OVLO divider levels and trip corners (part 6/6)
    Input voltage that puts a threshold on OVLO including pin leakage, for high and low trip corners.
    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
2026-10-06 test(pcb): rework SPICE limits as pass bands and control switches
    Typed voltage windows and ideal switches replace the old hall/AHCT/board power models.
    - hardware/pcb/tests/spice/electrical.py
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2026-10-06 test(pcb): add residual marker and render-output support for SPICE tests
    @residual(assumption) marks tests that record a known failure so review.md can list them (pushback finding).
    - hardware/pcb/tests/spice/residuals.py
    - hardware/pcb/tests/spice/support.py
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2026-10-06 test(pcb): check LED edges and R10 turn termination (part 2/2)
    Mutation: with R10 shorted the strongest SK9822 output undershoots past -0.3 V; since S6 R9's B.Cu run no longer needs help.
    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
2026-10-06 test(pcb): check hot-plug inrush inside the fuse pulse rule (part 3/8)
    I2t over the 8 ms ramp must stay under 20 % of nominal melting (Littelfuse Fuseology p3).
    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
2026-10-06 test(pcb): check OVLO window between supply and wrong adapter (4/8)
    User decision 2026-10-06: every in-spec supply turns on, a 6.0 V adapter is cut off at every corner.
    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
2026-10-06 test(pcb): check reversed plug is blocked (part 7/8)
    User decision D2: a reversed 12 V adapter must stay under the eFuse reverse pin current limit.
    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
2026-10-06 test(pcb): check plane drop with the mesh; start signals rework (8/8)
    Drop between J4 entry and any LED at approved and full brightness; start signals test rework.
    - hardware/pcb/tests/spice/test_signals.py
    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
2026-10-06 test(cad): add top-side clearance test setup (part 1/4)
    Reads the PCB pick-and-place output and checks parts clear the plate underside by 0.5 mm.
    - hardware/cad/tests/test_top_side_clearance.py
2026-10-06 test(cad): add rectangle and mated-zone helpers for clearance (part 2/4)
    Chebyshev gap to a point and overlap tests for connector mating zones.
    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
2026-10-06 feat(cad): measure overlap volume in validation; add assembly constants
    Seated case/plate/proxy overlap above 1 mm3 fails the build; project docstrings (part 1/2).
    - hardware/cad/core/validation.py
    - hardware/cad/projects/board-assembly/generate.py
    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
2026-10-06 feat(cad): check assembly fit; start case cavity rework (part 2/2)
    Render the finished and open views and fail if seated parts or the board proxy overlap; floor vent slots under the Pi.
    - hardware/cad/projects/board-case/generate.py
    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
2026-10-06 feat(cad): add microSD slot and Pi vents; start plate rework (4/4)
    Right-wall slot reaches the Pi's SD socket; case exceeds a desktop printer so sizes are quoted from a print service.
    - hardware/cad/projects/tile-plate/generate.py
    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
2026-10-06 docs: drop board I2C pull-ups from host notes; start protection text
    R1/R2 were removed, only the Pi's ~1.8 kohm remain; 400 kHz fails the SDA rise-time limit in simulation so keep 100 kHz.
    - docs/host.md
    - docs/power.md
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2026-10-06 docs: describe PCB verification layers
    README separates source calculation, SPICE, board tests and what physical evidence is still missing.
    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
2026-10-20 feat(firmware): wire control-panel buttons into startup (#65)
    * feat(firmware): wire control-panel buttons into startup
    * fix(firmware): report button panel startup outcomes
2026-10-21 ci(firmware): require release tags to name the firmware version (#78)
    Devices compare their Cargo version with the latest release tag, so the
    Firmware workflow now fails when the workspace and Yocto manifest
    versions differ or a v* tag does not name them. Tags with a pre-release
    suffix are published as GitHub prereleases, which /releases/latest
    skips. The release steps in docs/development.md describe the bump.
2026-10-23 refactor: generate repeated collection traits and button pins with macros (#80)
    The five core collections hand-wrote identical Default, Debug, borrowing
    IntoIterator and iteration-order comparison/hash impls. Two internal
    macros now generate them from each collection's new/len/iter/iter_mut.
    GPIOPins declared every button's field, BCM number and label separately
    in the struct, get() and its test. button_pins! now generates them from
    one hand-maintained table; the test keeps its independent expected
    wiring, and GPIOPins::COUNT replaces a hard-coded 12.
2026-10-23 refactor(logger): generate the per-level macros from one definition (#88)
    `define_level_macros!` generates `error!`, `warn!`, `info!`, `debug!` and `trace!` with their docs. `log!` is unchanged.
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2026-10-23 refactor(persistence): parse the record envelope through a Header type (#81)
    Replaces the hand-sliced decode with a private `Header` (`to_bytes`/`parse`/`metadata`) and `read_u16`/`read_u32` helpers, deriving every range from the offset constants. Encoded bytes are unchanged; the existing record tests pin them.
2026-10-23 refactor(pcb): place strip parts and squares through helpers (#101)
    Replaces 39 repeated `place(...)` blocks with `_place_strip`, builds the J1 header from a pin-to-net dict defaulting to `UNUSED`, and splits `_add_squares` into LED/sensor/bypass/termination helpers with named constants. Full generation before and after gave byte-identical netlist, layout, positions, BOM, KiCad PCB and schematic.
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2026-10-24 refactor(chess): name the board geometry and simplify insufficient-material (#89)
    Adds `Square::FILES`/`RANKS`/`is_light()`, file/rank accessors and `Color::index`, replaces the bare 8/64/56/63 literals across the square, square-set, setup and adapter code, and rewrites `is_insufficient` as a predicate over a `MaterialSummary`. No behaviour change.
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2026-10-24 refactor(chess): name hash tags and write them through a HashWriter (#91)
    Replaces the bare tag bytes with generated `#[repr(u8)]` tag enums and a `HashWriter` that dedupes the ply/hash/color/square update sequences. Adds golden-hash tests (41 event vectors, 2 board anchors) captured from the previous implementation, so the encoding is pinned byte-for-byte.
2026-10-24 refactor(firmware): name the SSD1309 commands and sizes (#94)
    Adds a `command` constants module, builds the init table from it, ties packet size and chunking to one `CHUNK` constant, adds `FRAME_BYTES`, and makes `commands()` return an error instead of panicking on more than 3 bytes. The init table and packet layout are unchanged.
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2026-10-24 feat(firmware): tune button timing from /etc/default/firmware (#106)
    Add a `tuning` module whose single `tuning!` declaration generates the
    ButtonTuning group, the Tuning aggregate, the FIRMWARE_* variable table and
    env-file rendering. main.rs loads Tuning::from_env() before startup: overrides
    are logged, unknown FIRMWARE_* names warn, invalid values fail startup with
    the variable and its range.
    The button poll interval (5 ms) and debounce (20 ms) now come from
    ButtonTuning through ButtonPanel. The image installs the rendered, commented
    env file as the /etc/default/firmware conffile, read by firmware.service via
    EnvironmentFile=; a test keeps the shipped file identical to the declaration.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
2026-10-24 ci: skip Blender on PRs that do not touch hardware (#132)
    * ci: skip Blender on PRs that do not touch hardware
    Changed scopes diffed base..head, so a pull request whose base branch had moved ahead was charged with the base's newer commits; any hardware change there re-rendered PCB and CAD on unrelated PRs. Diff from the merge base (base...head) instead.
    Also stop treating lint and tool configuration as unknown: clippy.toml and deny.toml are Rust scope, hardware/shared and pyproject.toml are hardware scope (no Rust reads hardware/), and a new quality scope runs only the Quality job for tooling/, the ast-grep, ls-lint, typos and EditorConfig configs and .githooks/. Unknown paths still run ev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
2026-10-25 chore(firmware): adopt a workspace lint policy (#107)
    * chore(firmware): adopt a workspace lint policy
    Add `[workspace.lints]` (correctness/suspicious deny, pedantic, no unsafe,
    unreachable_pub, Debug on public types, unwrap/expect and printing outside
    tests, reasons on every allow) and a root clippy.toml with function limits and
    disallowed APIs: the environment outside `tuning`, shelling out, and Tokio
    channels outside `events`.
    The firmware opts in and is fixed rather than allowed: visibility narrowed,
    Debug and `# Errors` docs added, argument lists grouped, and the few
    deliberate exceptions scoped with a reason.
    * test(firmware): compare empty results with assert_eq
    Rust 1.99's pedant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
2026-10-25 chore(hardware): limit Python complexity and argument counts (#113)
    * chore(hardware): limit Python complexity and argument counts
    Enable Ruff's McCabe (max 15) and Pylint rules (max five arguments) and
    refactor what they report without changing behaviour: long validators and
    renderers become ordered helpers, and long parameter lists become small frozen
    dataclasses or typed keyword options. Physical values and contracts are
    unchanged. Lazy pcbnew/bpy imports and constant comparisons are ignored with
    reasons; component constructors keep one keyword per pin net.
    * fix(hardware): compare only the plate's x and y with its outline
    The outline check zipped the plate's (x, y) with the three-axis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
2026-10-25 chore(hardware): enable Ruff bug, style and print rules (#114)
    Add flake8-bugbear, simplify, pyupgrade, print, return and pathlib rules.
    Every zip over paired data now states `strict=True` (each pair is
    equal-length by construction); command-line entry points keep printing
    through per-file ignores.
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

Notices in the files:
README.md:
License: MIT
